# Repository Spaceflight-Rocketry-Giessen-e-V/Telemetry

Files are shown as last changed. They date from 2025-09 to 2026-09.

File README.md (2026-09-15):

# ASCENT Experimental Rocket Telemetry System

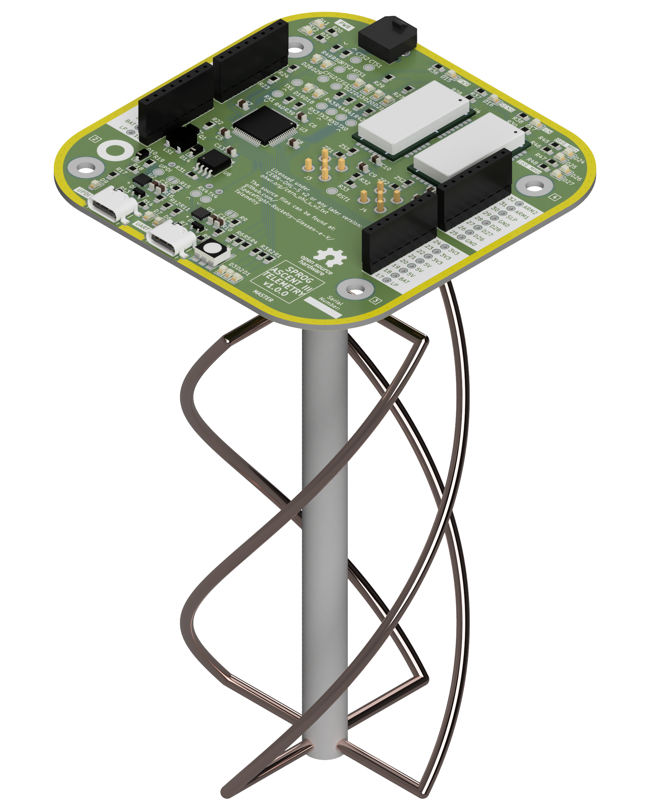
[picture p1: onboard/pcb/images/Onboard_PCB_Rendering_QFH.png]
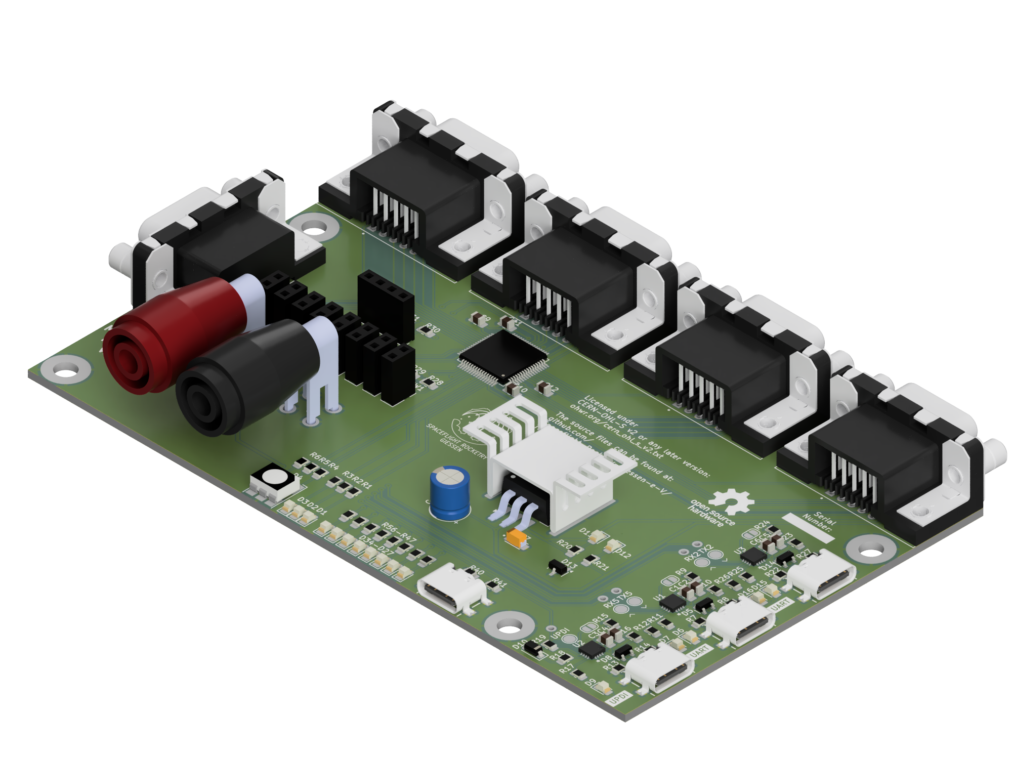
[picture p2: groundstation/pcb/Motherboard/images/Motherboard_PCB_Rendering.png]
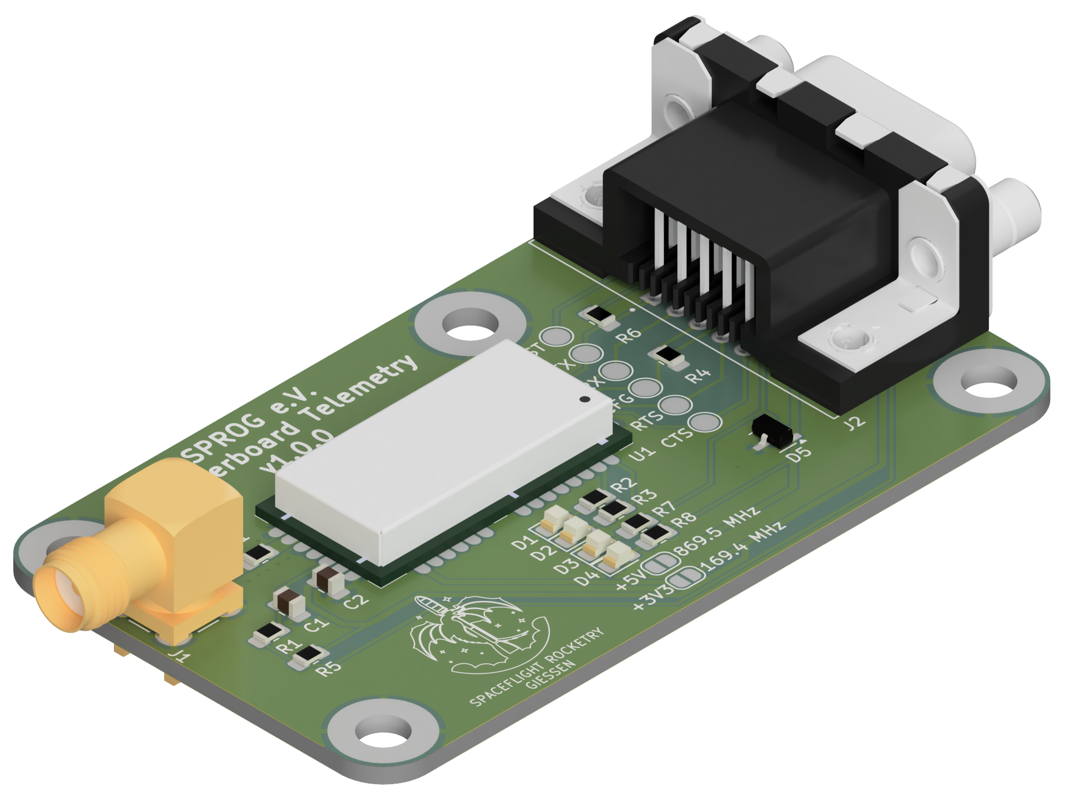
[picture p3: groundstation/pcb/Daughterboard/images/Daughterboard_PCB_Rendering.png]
|</p> | </p></p>|
|---|---|
|<p align="center">[The Onboard System](/onboard/)</p>|<p align="center">[The Groundstation System](/groundstation/)</p>|

---

## Overview

The ASCENT telemetry system is part of the ASCENT flight computer of the student rocketry club [Spaceflight Rocketry Gießen e.V.](https://sprog-ev.de/en/), which is being developed for the PIPE and ARCHER experimental rockets.
This dual-frequency 169/869 MHz telemetry system based on Radiocrafts RC232 radio modules allows bidirectional data exchange between rockets and groundstations with a range of 20 km and a minimum data rate of 1.2 kbps.
The design can easily be adapted for uses outside of rocketry like Smart Home or RC.



## Basic Functionality

- Receiving flight data from the rocket
- Sending radio commands to the rocket
- Displaying live telemetry on a serial monitor or UI

## Actual Performance

In January 2026, we performed our first long range test over a distance of 2 km. Despite poor weather conditions and objects inside the first Fresnel zone, the received signal strength was on par with the theoretical maximum without any unaccounted losses. This test ruled out major design flaws.



This excellent performance was confirmed by multiple medium range tests.

In April 2026, the system was successfully tested on the PIPE 2 rocket to an altitude of 350 m and experienced no link issues during the whole flight.

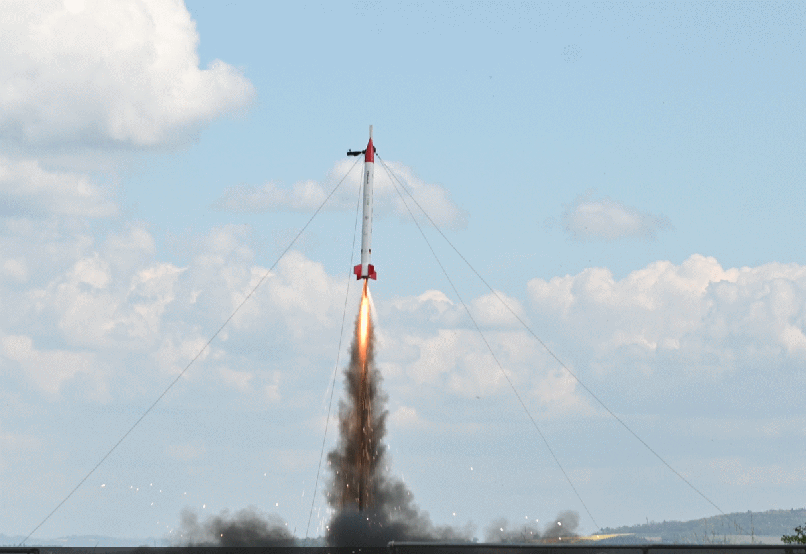
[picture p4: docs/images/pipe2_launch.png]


---

## Repository Contents

This repository contains all files necessary to reproduce the telemetry system, including hardware, firmware, software, and documentation.

### 1. Antenna Hardware

So far, this repository includes [design files](/groundstation/antenna/helical/) and [assembly instructions](/docs/helical_antenna_assembly_manual.md) for our helical 869 MHz groundstation antenna.

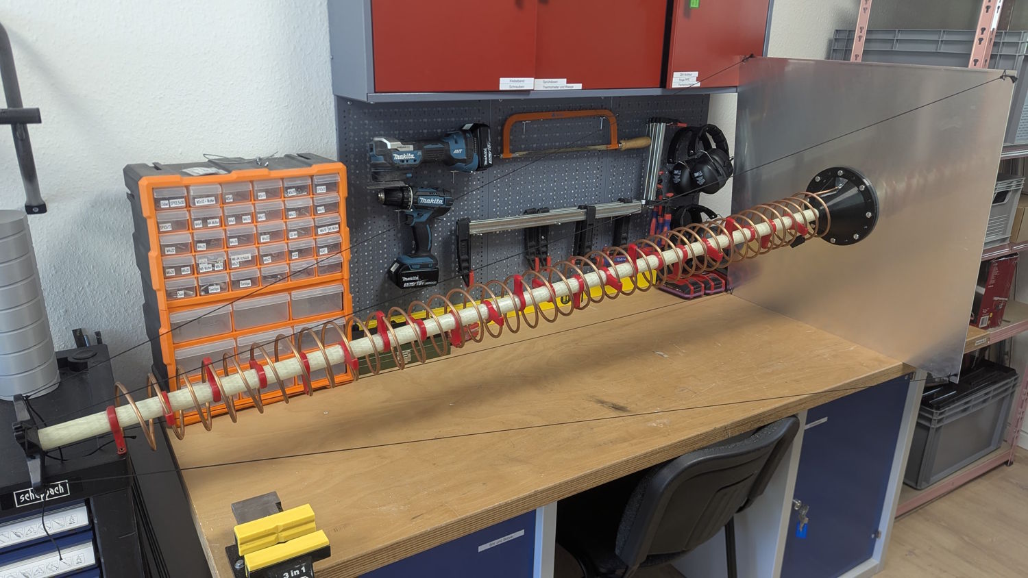
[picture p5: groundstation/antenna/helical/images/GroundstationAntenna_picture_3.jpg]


We also do our own FDTD-simulations which can be found [here](groundstation/antenna/helical/Simulation/Helical_Antenna.m).

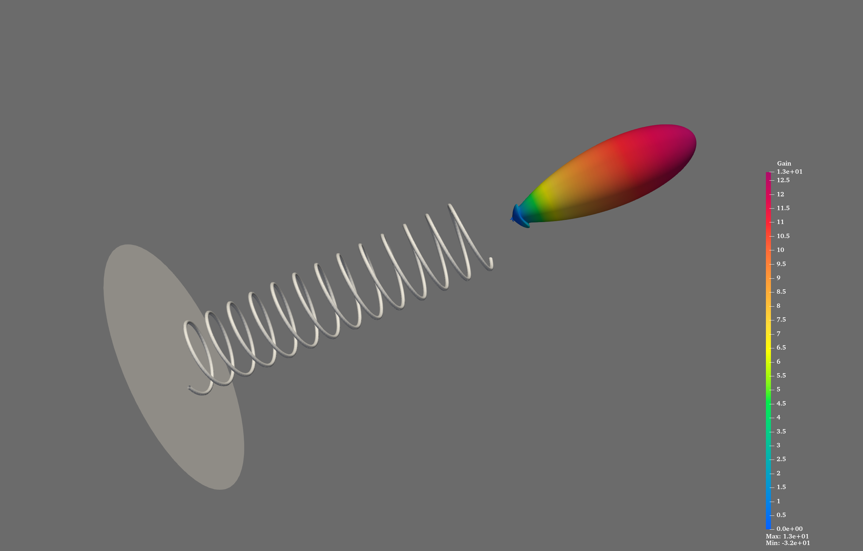
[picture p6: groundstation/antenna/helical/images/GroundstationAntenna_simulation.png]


Currently, we are developing an 869 MHz QFH antenna.

### 2. Electronics Hardware

The telemetry system is based on separate [onboard](/onboard/pcb/) and [groundstation](/groundstation/pcb/) electronics.
The groundstation uses a modular approach with a [motherboard](/groundstation/pcb/Motherboard/) to which up to four [daughterboards](/groundstation/pcb/Daughterboard/) with radio modules can be connected.

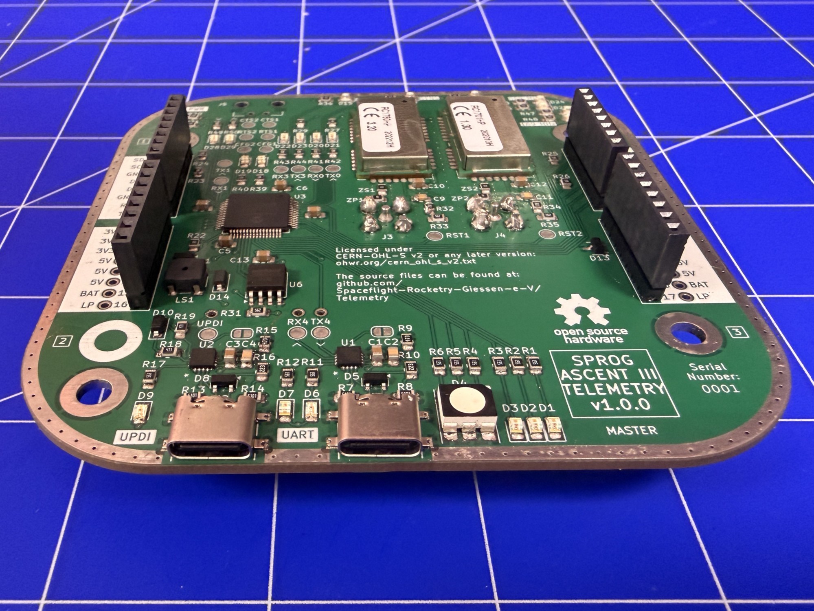
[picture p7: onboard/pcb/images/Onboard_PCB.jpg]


The repository includes for each system the KiCad design files including custom component schematic, footprint, and 3D model libraries, the PDF schematic, the Gerber production files, the bill of material (BOM) and an interactive BOM (iBOM). 
Renderings, images, and 3D models of the electronics are also included.

The [onboard mounting structure](/onboard/mounting%20structure/), the [motherboard and daughterboard casings](/groundstation/casing/) are included separately.

### 3. Firmware

- [Onboard Firmware](/onboard/firmware/)
- [Groundstation Firmware](/groundstation/firmware/) 
- [Radiocrafts RC17xHP-RC232 Library](/libraries/Radiocrafts_RC17xxHP_RC232/)
- [Dynamic Package Codec (Encoding/Decoding) Library](/libraries/DynamicPacketCodec/)
- [Firmware Functions/Classes Reference](https://spaceflight-rocketry-giessen-e-v.github.io/Telemetry/)

### 4. Groundstation UI Software

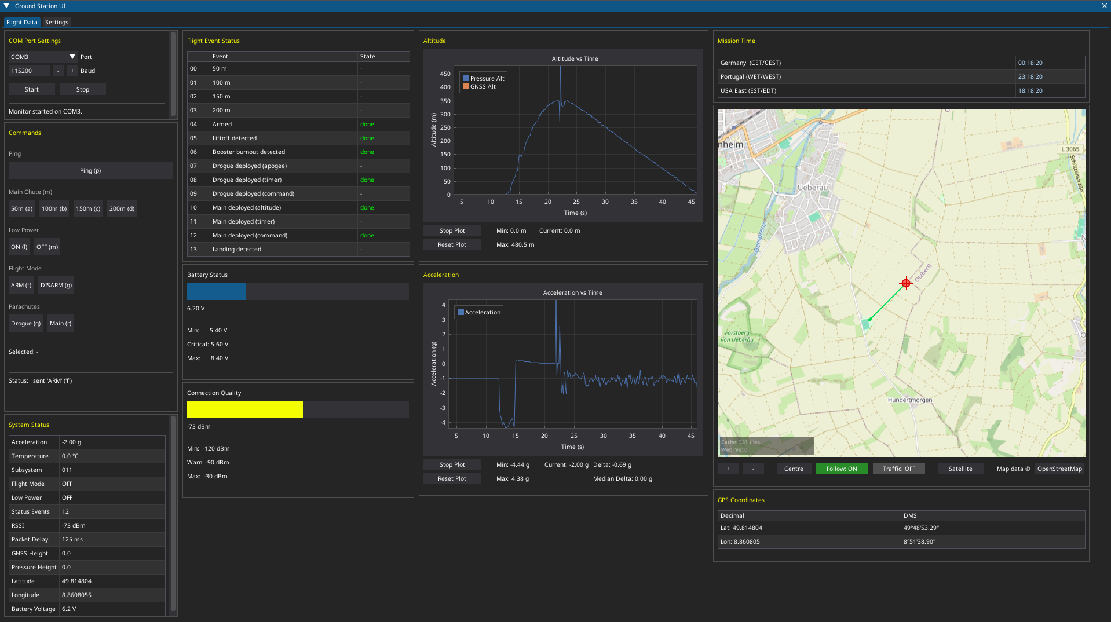
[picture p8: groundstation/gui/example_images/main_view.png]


[Python-based software](/groundstation/gui/) to display live telemetry data on a modern, minimalistic interface with the ability to store flight data and send radio commands. 

Widgets include a GNSS map view, a height plot over time, a acceleration plot over time, a battery voltage indicator with visual warnings, a connection quality indicator with visual warnings and a status event indicator.

### 5. Documentation

- [User Manual](/docs/user_manual.md) and [Operations Cheatsheet](/docs/operations_cheatsheet.md)
- [Design Overview/Rationals](/docs/design_overview.md)
- Documentation of the [Packet Structure](/docs/packet_structure.md) and the [Linkbudget Calculation](/docs/linkbudget.ipynb)
- [And more...](/docs/)

---

## Legal Notice

Please note that radio systems may be subject to local regulations. Ensure that any testing or deployment of these systems complies with national and regional laws regarding RF transmission. The project maintainers are not responsible for misuse or regulatory violations.  

## License

Copyright Spaceflight Rocketry Giessen e.V. 2026<br />
This source describes Open Hardware and is licensed under the CERN-OHL-S v2.<br />
You may redistribute and modify this source and make products using it under the terms of the [CERN-OHL-S v2 or any later version](LICENSE).<br />
This source is distributed WITHOUT ANY EXPRESS OR IMPLIED WARRANTY, INCLUDING OF MERCHANTABILITY, SATISFACTORY QUALITY AND FITNESS FOR A PARTICULAR PURPOSE. Please see the CERN-OHL-S v2 for applicable conditions.<br />
Source location: https://github.com/Spaceflight-Rocketry-Giessen-e-V/Telemetry<br />
As per CERN-OHL-S v2 section 4, should you produce hardware based on this source, you must where practicable maintain the Source Location in its documentation or license information.<br />

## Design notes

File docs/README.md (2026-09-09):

# Documentation

- [Design Overview](/docs/design_overview.md)
    - Design Details
    - Design Rationals
- [User Manual](/docs/user_manual.md)
    - Assembly Instructions
    - Operation Advices
- Libraries Documentation
    - [Radiocrafts RC17xxHP-RC232](/libraries/Radiocrafts_RC17xxHP_RC232/README.md)
    - [Dynamic Packet Codec](/libraries/DynamicPacketCodec/README.md)
- Antenna Documentation
    - [Helical Antenna Design Guide](/docs/helical_antenna_design_guide.ipynb)
    - [Helical Antenna Assembly Manual](/docs/helical_antenna_assembly_manual.md)
    - [Helical Antenna Simulation Guide](/docs/helical_antenna_simulation_guide.md)
    - [QFH Antenna CAD Tutorial](/docs/qfh_antenna_cad_tutorial.md)
- [Operations Cheatsheet](/docs/operations_cheatsheet.md)
    - Commands List
    - Status Events List
    - LED List
- [Packet Structure](/docs/packet_structure.md)
    - General Structure
    - Component Details
- [Linkbudget](/docs/linkbudget.md)
    - Theoretical Foundation
    - Example Calculations

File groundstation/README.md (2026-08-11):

# The Groundstation System

- [Motherboard Electronics Hardware](/groundstation/pcb/Motherboard/)
    - [KiCad Design Files](/groundstation/pcb/Motherboard/)
    - [PDF Schematic](/groundstation/pcb/Motherboard/TelemetryGroundstationMB_Schematic.pdf)
    - [Interactive Schematic / iBOM](/groundstation/pcb/Motherboard/TelemetryGroundstationMB_iBOM.html)
    - [BOM](/groundstation/pcb/Motherboard/TelemetryGroundstationMB_BOM.csv)
    - [Gerber Files](/groundstation/pcb/Motherboard/Production%20Files/)
    - [PCB 3D Model](/groundstation/pcb/Motherboard/TelemetryGroundstationMB.step)
    - [PCB Images](/groundstation/pcb/Motherboard/images/)
- [Daughterboard Electronics Hardware](/groundstation/pcb/Daughterboard/)
    - [KiCad Design Files](/groundstation/pcb/Daughterboard/)
    - [PDF Schematic](/groundstation/pcb/Daughterboard/TelemetryGroundstationDB_Schematic.pdf)
    - [Interactive Schematic / iBOM](/groundstation/pcb/Daughterboard/TelemetryGroundstationDB_iBOM.html)
    - [BOM](/groundstation/pcb/Daughterboard/TelemetryGroundstationDB_BOM.csv)
    - [Gerber Files](/groundstation/pcb/Daughterboard/Production%20Files/)
    - [PCB 3D Model](/groundstation/pcb/Daughterboard/TelemetryGroundstationDB.step)
    - [PCB Images](/groundstation/pcb/Daughterboard/images/)
- [Electronics Casings](/groundstation/casing/)
    - [Motherboard Casing](/groundstation/casing/Motherboard)
    - [Daughterboard Casing](/groundstation/casing/Daughterboard)
- [Firmware](/groundstation/firmware/)
- [869 MHz Helical Antenna](/groundstation/antenna/helical/)
    - [Design Files](/groundstation/antenna/helical/)
    - [Design Guide](/docs/helical_antenna_design_guide.ipynb)
    - [Assembly Manual](/docs/helical_antenna_assembly_manual.md)
    - [Antenna 3D Model](/groundstation/antenna/helical/Antenna%20Assembly.step)
    - [Antenna Images](/groundstation/antenna/helical/images/)
    - [Simulation](/groundstation/antenna/helical/Simulation/)
    - [Simulation Guide](/docs/helical_antenna_simulation_guide.md)
- [Serial Monitor Configuration File](/groundstation/Coolterm_SerialMonitor_Settings.CoolTermSettings)
- [Graphical User Interface](/groundstation/gui/)

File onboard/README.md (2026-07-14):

# The Onboard System

- [Electronics Hardware](/onboard/pcb/)
    - [KiCad Design Files](/onboard/pcb/)
    - [PDF Schematic](/onboard/pcb/TelemetryOnboard_Schematic.pdf)
    - [Interactive Schematic / iBOM](/onboard/pcb/TelemetryOnboard_iBOM.html)
    - [BOM](/onboard/pcb/TelemetryOnboard_BOM.csv)
    - [Gerber Files](/onboard/pcb/Production%20Files/)
    - [PCB 3D Model](/onboard/pcb/TelemetryOnboard.step)
    - [PCB Images](/onboard/pcb/images/)
- [Mounting Structure](/onboard/mounting%20structure/)
- [Firmware](/onboard/firmware/)
- [869 MHz QFH Antenna](/onboard/antenna/) (not yet available)

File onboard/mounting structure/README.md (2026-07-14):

# Electronics Mounting Structure

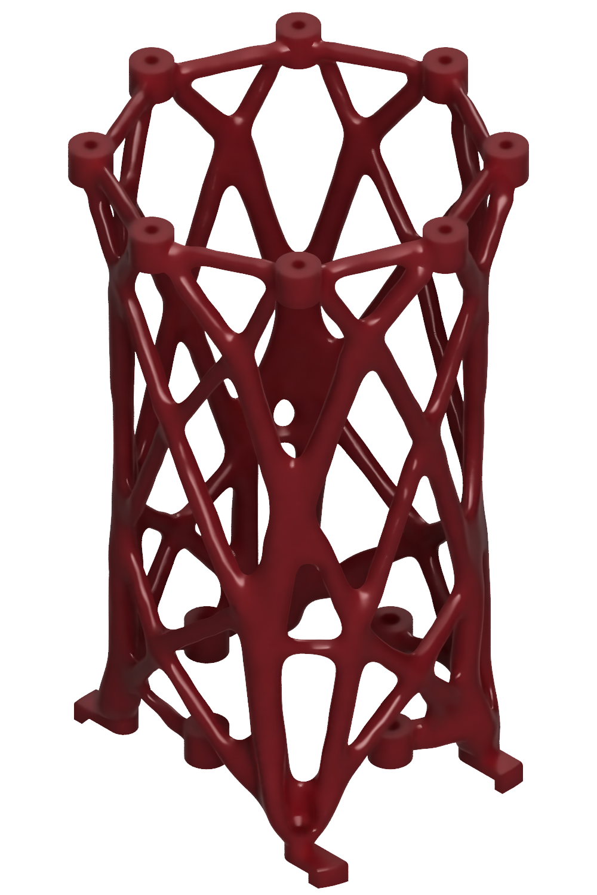
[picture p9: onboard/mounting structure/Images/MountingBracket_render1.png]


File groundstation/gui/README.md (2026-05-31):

# Ground Station UI

A desktop telemetry ground station for monitoring rocketry flights in real time. Built with Python and DearPyGui.

Ground Station UI

---

## Tech Stack

- **Python 3.11+**
- **[DearPyGui](https://github.com/hoffstadt/DearPyGui)** — immediate-mode GUI framework
- **pyserial** — serial communication with the telemetry receiver
- **zoneinfo** — multi-timezone mission clock (stdlib)

---

## UI Overview

The interface is split into two tabs: Flight Data and Settings.

**Flight Data** shows:
- COM port controls (port selector, baud rate, start/stop)
- Command panel with a two-step confirm/abort flow before anything is sent
- Flight event status table (sequential, colour-coded)
- Battery voltage and connection quality (RSSI) progress bars
- Live altitude and acceleration plots with stop/reset/statistics controls
- System status table with the latest decoded packet fields
- Map view with live GPS tracking
- Mission clock in three time zones (Germany, Portugal, US East)

---

## Configuration

All thresholds and labels live in `settings.json` (auto-created on first run). You can edit them through the Settings tab at runtime — changes are written to disk immediately.

Configurable sections:

| Section | What you can change |
| --- | --- |
| `battery` | min / max / critical voltage |
| `connection` | RSSI min / warn / max |
| `flight_events` | event labels, abort threshold |
| `commands` | command groups, button labels, serial codes |

---

## Project Structure

```
├── telemetry/
│   ├── com_controller.py          # Serial receiver thread
│   └── com_monitor_controller.py  # UI-side serial control panel
├── ui/
│   ├── ui_manager.py              # Top-level update dispatcher
│   ├── settings_manager.py        # JSON-backed settings store
│   ├── acceleration_window.py
│   ├── altitude_window.py
│   ├── battery_window.py
│   ├── commands_window.py
│   ├── connection_window.py
│   ├── flight_events_window.py
│   ├── last_packet_window.py
│   ├── location_window.py
│   ├── map_view_window.py
│   ├── settings_window.py
│   └── time_window.py
└── settings.json                  # Auto-generated, edit via Settings tab
```

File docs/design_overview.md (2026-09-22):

# Design Overview

This document provides detailed information about our electronics, firmware, antenna, and GUI systems. It also covers rationales used during the design process.



The whole system is designed for an effective range of 18 km. To accomplish this goal, the signal strength at the receiver must be strong enough to be processed. Our link budget calculation as outlined in [this document](linkbudget.ipynb) ensures that our system meets this requirement.

---

# Table of Contents

- [Electronics](#electronics)
  - [Design Overview](#design-overview-1)
    - [Groundstation MB/DB Approach](#groundstation-mbdb-approach)
    - [Onboard Electronics](#onboard-electronics)
  - [Design Details](#design-details)
    - [Radio Frequencies](#radio-frequencies)
    - [Radio Modules](#radio-modules)
    - [Microcontroller](#microcontroller)
    - [PCB Stackup](#pcb-stackup)
    - [RF Traces](#rf-traces)
    - [USB UPDI Programmer](#usb-updi-programmer)
    - [Staggered Pin Rows / Lock Pattern](#staggered-pin-rows--lock-pattern)
  - [Groundstation Electronics Casings](#groundstation-electronics-casings)
  - [Onboard Electronics Mounting Structure](#onboard-electronics-mounting-structure)
- [Firmware](#firmware)
  - [Onboard Firmware](#onboard-firmware)
  - [Groundstation Firmware](#groundstation-firmware)
  - [Data Budget \& Packet Structure](#data-budget--packet-structure)
  - [Libraries](#libraries)
    - [Radiocrafts RC17xxHP-RC232](#radiocrafts-rx17xxhp-rc232-library)
    - [Dynamic Packet Codec](#dynamic-packet-codec-library)
- [Antennas](#antennas)
  - [Groundstation 869 MHz Helical Antenna](#groundstation-869-mhz-helical-antenna)
    - [Geometric Design](#geometric-design)
    - [Mechanical Design](#mechanical-design)
    - [Simulations](#simulations)
  - [Groundstation 169 MHz Dipole Antenna](#groundstation-169-mhz-dipole-antenna)
  - [Onboard 869 MHz QFH Antenna](#onboard-869-mhz-qfh-antenna)
    - [Geometric Design](#geometric-design-1)
    - [Mechanical Design](#mechanical-design-1)
    - [Simulations](#simulations-1)
- [GUI software](#gui-software)
  - [Architecture](#architecture)
  - [Flight Data Tab](#flight-data-tab)
  - [Settings Tab](#settings-tab)
  - [Data Flow \& Logging](#data-flow--logging)

---

# Electronics

## Design Overview

### Groundstation MB/DB Approach

|  |  |
| :---: | :---: |
| [Motherboard](/groundstation/pcb/Motherboard/)| [Daughterboard](/groundstation/pcb/Daughterboard/)|

The system is based on a modular approach consisting of a motherboard and one or more daughterboards. The motherboard integrates the microcontroller (AVR128DB64), while the daughterboards host the radio modules (RC17xx series).

This architecture allows multiple daughterboards to be connected to the motherboard via a standard 15-pin VGA connector. As a result, different radio modules operating on different frequency bands can be used within the same system.

In the current configuration, the system is designed to use 169.5 MHz for command transmission and 869.5 MHz for telemetry data.

The use of the LEDs is described in the [operations cheatsheet](operations_cheatsheet.md).

### Onboard Electronics

The onboard PCB is based on the standard layout of our rocketry club, featuring a square design with round edges. Power and data are distributed via stackable pin headers located on the left and right sides. Generally, cheap stackable headers which can be found on eBay or Aliexpress can be used. We opted to use [Samtec ESQ pin sockets](https://www.digikey.de/de/products/detail/samtec-inc/ESQ-108-13-G-S/1766188) due to their superior quality. An I2C connection is used for communication with other subsystems to gather sensor data and forward radio commands.

The system includes an RGB LED for status indication, three LEDs for subsystem status indication and five general-purpose LEDs. Additionally, all UART traces feature a LED indicator.

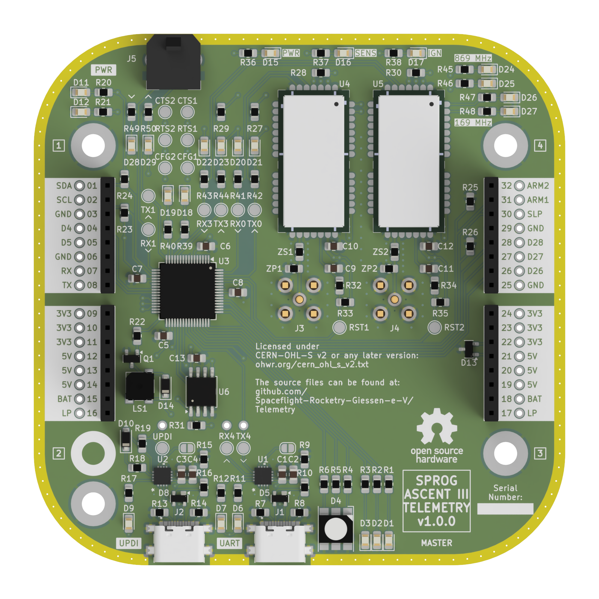
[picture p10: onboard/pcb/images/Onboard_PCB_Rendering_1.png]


### Previous Design

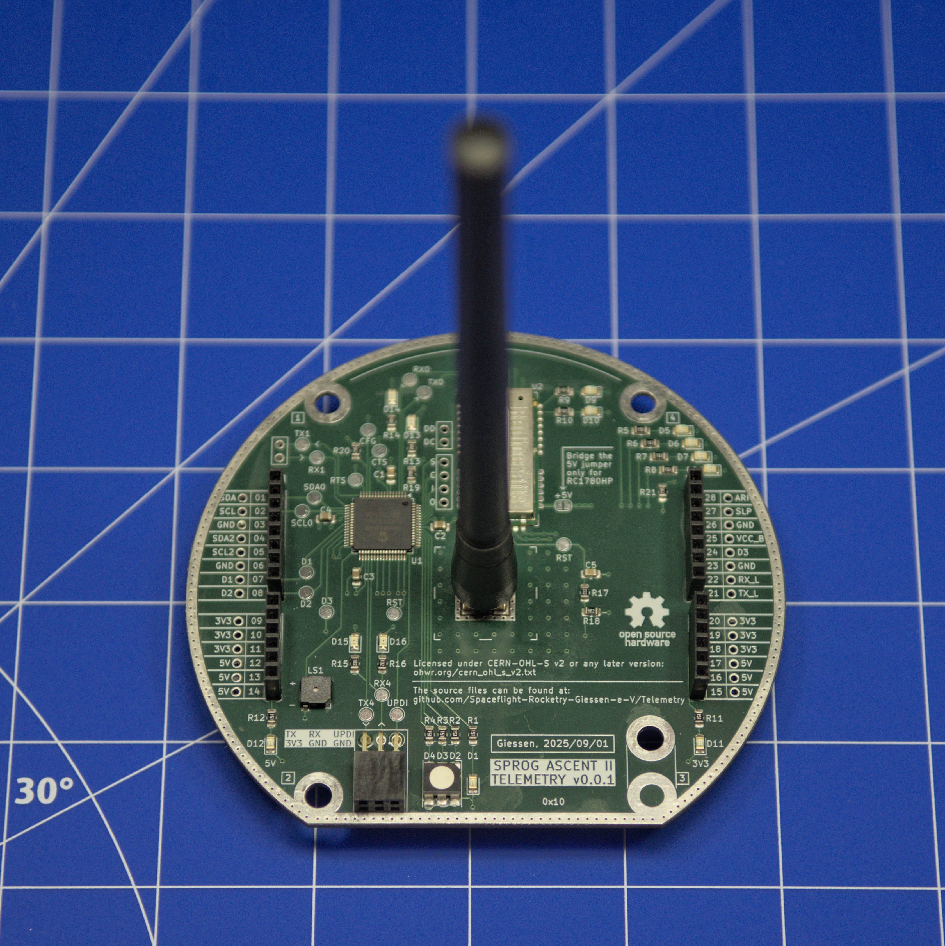
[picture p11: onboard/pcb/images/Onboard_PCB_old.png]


## Design Details

### Radio Frequencies

The license-free frequency bands in Germany are regulated by the Bundesnetzagentur. Frequencies between 100 MHz and 2400 MHz are of primary interest to us. The relevant regulations can be found in the ["Allgemeinzuteilungen von Frequenzen"](https://www.bundesnetzagentur.de/DE/Fachthemen/Telekommunikation/Frequenzen/Allgemeinzuteilungen/start.html). In this case the regulation of SRD devices applies. 

The frequency band between 169.4 MHz and 169.475 MHz can be used with an output power (EIRP) of up to 27 dBm or 500 mW, with a duty cycle of 1 %. This limits the radio transmission to 36 seconds total per (continous) hour.



The frequency band between 869.4 MHz and 869.65 MHz can be used with an output power (EIRP) of up to 27 dBm or 500 mW, with a duty cycle of 10 %. This limits the radio transmission to 6 minutes total per (continous) hour.



### Radio Modules

We chose the Radiocrafts RC17xxHP-RC232 radio modules which come in 169 MHz (RC1701HP) and 869 MHz (RC1780HP) variants. The modules can achieve output powers of up to 27 dBm and the operation is straightforward due to the UART interface. The datasheet can be found [here](https://radiocrafts.com/uploads/RC17xxHP-RC232_Datasheet.pdf). Additionally, there is a separate manual for the RC232 series of radio modules that includes all configuration commands and more information, available [here](https://radiocrafts.com/uploads/RC232_user_manual.pdf). Application notes can be downloaded [here](https://radiocrafts.com/resources/document-library/?rs=Application%20Notes).

The following tables show the available data rates and high power (27 dBm) radio channels of the RC1780HP-RC232 and RC1701HP-RC232 radio modules. The data is taken from the linked datasheet.

|Date Rate #|Data rate|Bandwidth|Modulation|
|---|---|---|--|
|1|tbd.|||
|2|0.3 kbit/s|12.5 kHz|2GFSK|
|3|0.6 kbit/s|12.5 kHz|2GFSK|
|**4**|**1.2 kbit/s**|**12.5 kHz**|**2GFSK**|
|5|2.4 kbit/s|12.5 kHz|2GFSK|
|6|tbd.|||
|7|4.8 kbit/s|12.5 kHz|2GFSK|
|8|9.6 kbit/s|12.5 kHz|4GFSK|
|9|9.6 kbit/s|25 kHz|2GFSK|
|10|19.2 kbit/s|50 kHz|4GFSK|
|11|tbd.|||
|12|38.4 kbit/s|100 kHz|2GFSK|
|13|50 kbit/s|100 kHz|2GFSK|
|14|76.8 kbit/s|200 kHz|2GFSK|
|15|100 kbit/s|200 kHz|2GFSK|

**RC1780HP-RC232 +27 dBm Channels**

|Channel #|Center Frequency|
|---|---|
|57|869.412500 MHz|
|59|869.437500 MHz|
|58|869.462500 MHz|
|60|869.487500 MHz|
|**61**|**869.512500 MHz**|
|62|869.537500 MHz|
|63|869.562500 MHz|
|64|869.587500 MHz|
|65|869.612500 MHz|
|66|869.637500 MHz|

**RC1701HP-RC232 +27 dBm Channels**

|Channel #|Center Frequency|
|---|---|
|**1**|**169.406250 MHz**|
|2|169.418750 MHz|
|3|169.431250 MHz|
|4|169.443750 MHz|
|5|169.456250 MHz|
|6|169.468750 MHz|
|7|169.412500 MHz|
|8|169.437500 MHz|
|9|169.462500 MHz|
|10|169.437500 MHz|

### Microcontroller

We use the AVR128DB64 microcontroller in the 64-pin LQFP version ([datasheet](https://ww1.microchip.com/downloads/en/DeviceDoc/AVR128DB28-32-48-64-DataSheet-DS40002247A.pdf)). It offers a decent improvement compared to beginner-friendly Arduino boards, while still being easy to use. The [AVR DB Arduino Core (DxCore)](https://github.com/SpenceKonde/DxCore) offers excellent firmware and hardware documentation.

The following image shows the pinout of the AVR128DB64 MCU and is taken from the DxCore documentation:



### PCB Stackup

The electronics design (schematic and pcb) was done with the open source EDA software KiCad. We included the KiCad project with all necessary files.

During the pcb design process, we considered the Radiocrafts [RF PCB Layout Recommendation Application Note](https://radiocrafts.com/uploads/AN061_RF_PCB_Layout_Recommendations.pdf) and a [RF PCB Design Guide](https://www.proto-electronics.com/blog/routing-guidelines-rf-pcb). The PCB has a basic 4-layer stackup intended to reduce electromagnetic interference:
1) Components, signal traces, 50 Ohm RF trace
2) Continous ground plane
3) 5 V and 3.3 V power plane
4) Ground plane, signal traces 

Around the edge of the PCB, an exposed ground strip is included, connected by many vias to the solid ground plane (layer 2). The intend is to contain any electromagnetic emissions.

### RF Traces

There are three types of traces commonly used as RF signal traces: microstrip, stripline, and coplanar waveguide. For all types, there are several online calculators to obtain the correct strip width to have a characteristic impedence of 50 Ohms. We use a coplanar waveguide and the calculator included in Kicad.

Some PCB properties like Tmet, RHO, RGH, H, Er, and tand cannot be changed and depend on the PCB manufacturer. JLCPCB lists some parameters like Tmet, H, and Er in [this document](https://jlcpcb.com/impedance). For the other parameters, we used standard values.

For a 4 layer pcb like our onboard pcb: H = 0.2104 mm. For a 2 layer pcb like our groundstation daughterboard pcb: H = 1.6 mm.

For the groundstation daughterboard, our goal was to use the width of the 0805 matching component pads as the trace width and thus a variable separation S. The result is S = 0.22 mm:

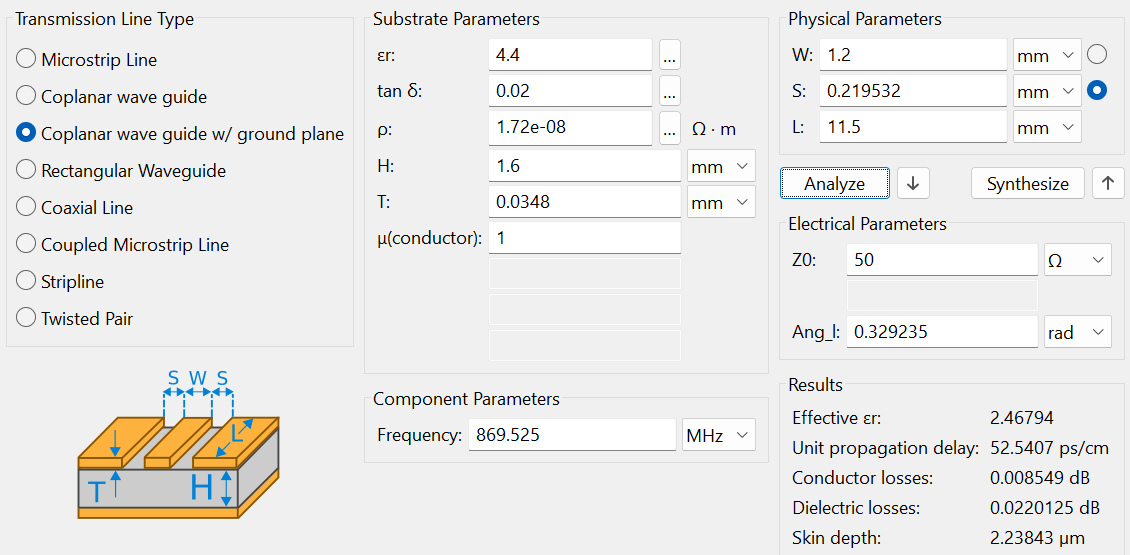
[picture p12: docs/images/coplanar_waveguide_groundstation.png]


Due to the different height of the onboard pcb, a trace width of 1.2 mm would lead to large values for S. Thus, we used a fixed separation S = 0.22 mm (same value as for the groundstation daughterboard) and a variable trace width. The result is W = 0.37 mm. Due to the different width of the matching components, this is not an ideal trace and might have a slighty different impedance. Matching is advised.

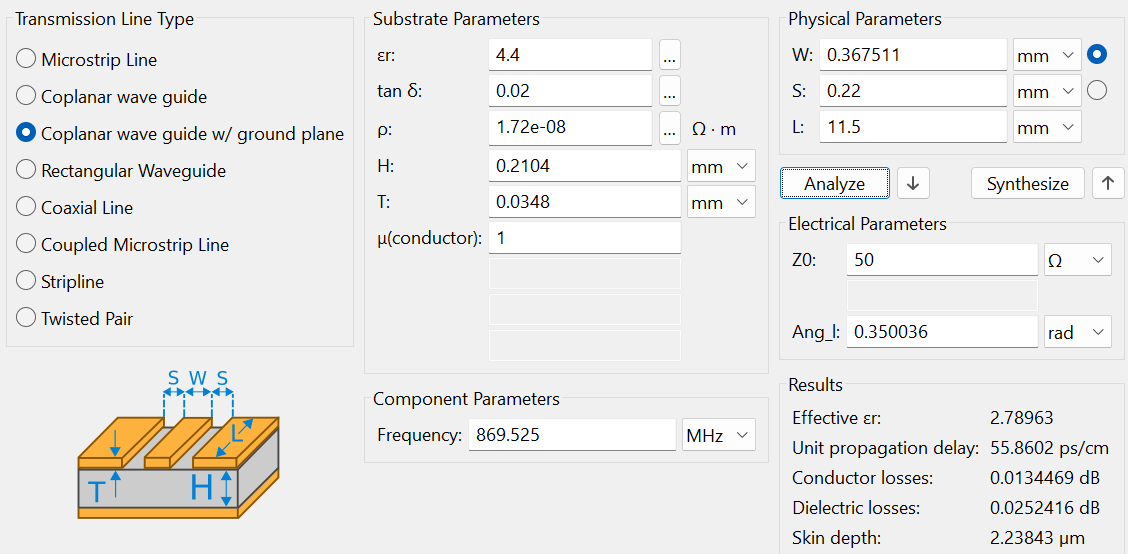
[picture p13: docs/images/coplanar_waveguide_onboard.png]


In the signal trace, a T-matching network is included to be able to match the antenna's impedance to 50 Ohms. When no matching is used, a 0 Ohms resistor has to be connected in series and the parallel component has to be left open. More informations about antenna matching can be found in the [user manual](user_manual.md).

### USB UPDI Programmer

On the onboard and motherboard PCBs, onboard UPDI programmers and USB-UART bridges with USB-C connectors are included. 

The following image shows the general schematic:

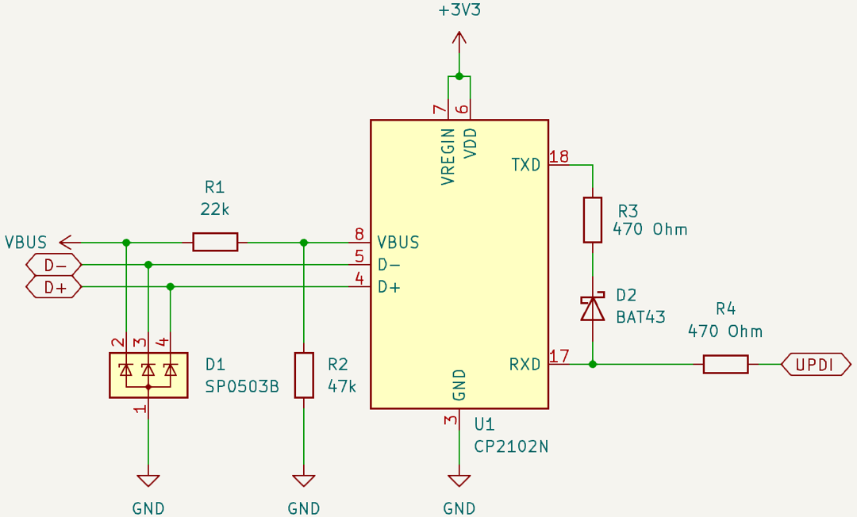
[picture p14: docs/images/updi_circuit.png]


The design features a CP2102N USB to UART bridge, [whose datasheet](https://www.silabs.com/documents/public/data-sheets/cp2102n-datasheet.pdf) suggests the use of an ESD protection diode (D1) for the data lines, and a voltage divider (R1, R2) for the `VBUS` input.
Not shown in the schematic is one LED (with a 560 Ohms resistor) each at `TXT` and `RXT` and decoupling capacitors (4.7 uF and 0.1 uF) at the `VREGIN` and `VDD`.

The UART to UPDI connection is based on [this guide](https://github.com/SpenceKonde/AVR-Guidance/blob/master/UPDI/jtag2updi.md). It features a Schottky diode and two protection resistors.

### Staggered Pin Rows / Lock Pattern

The onboard electronics feature a total of four stackable pin headers used to connect all subsystems of the rocket flight computer to a PCB stackup. Without precise alignment, the stacking of multiple PCBs is impossible.<br>
To fullfill this requirement, we use high-quality [Samtec ESQ pin sockets](https://www.digikey.de/de/products/detail/samtec-inc/ESQ-108-13-G-S/1766188) and a staggered pin layout inspired by an old [Sparkfun article](https://web.archive.org/web/20241202225923/https://www.sparkfun.com/tutorials/114), which is only available on the Wayback Machine nowadays.

The pins are staggered to guarantee perfect alignment. A shift by 1/10" or 0.254 mm and a hole size of 1 mm is perfect for the Samtec ESQ pin sockets. The result looks like this:

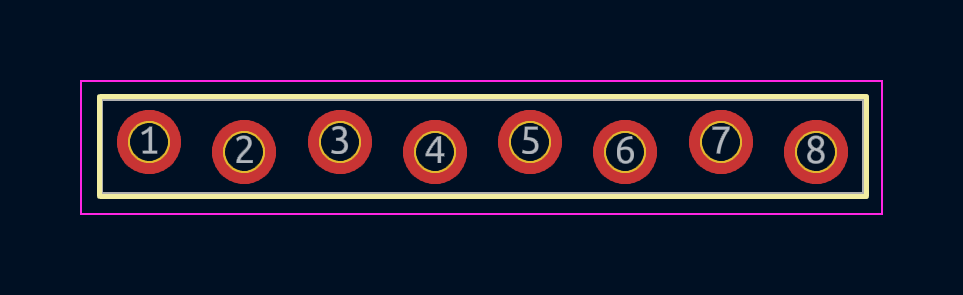
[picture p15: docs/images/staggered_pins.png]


## Groundstation Electronics Casings

Plastics enclosures for the motherboard and daughterboards, each with a bottom part, a shell, and an acrylic cover. The repository includes all the original Fusion and auxiliary (`.step`, `.stl`) design files.

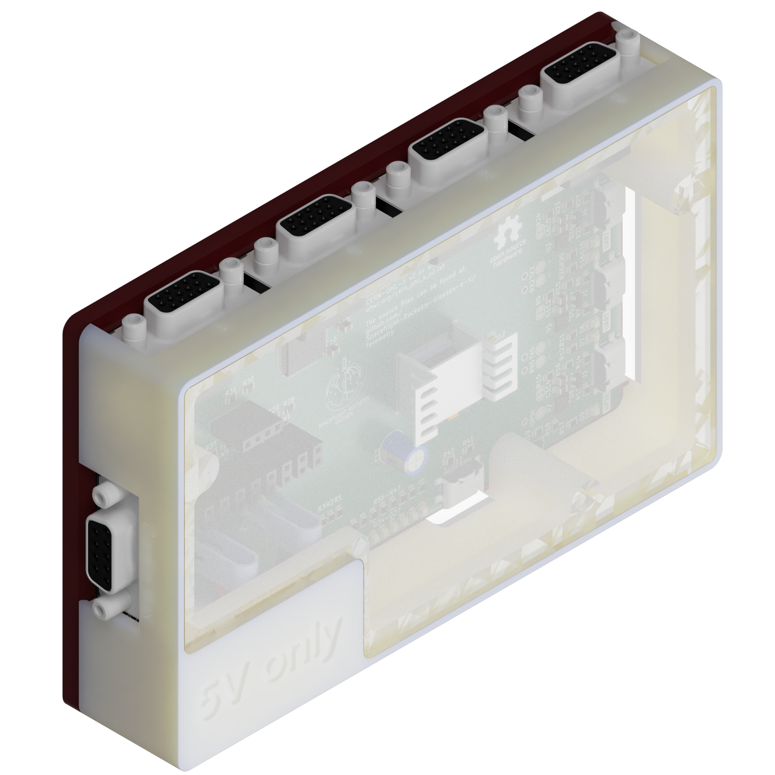
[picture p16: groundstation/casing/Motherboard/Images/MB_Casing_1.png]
Motherboard Casing
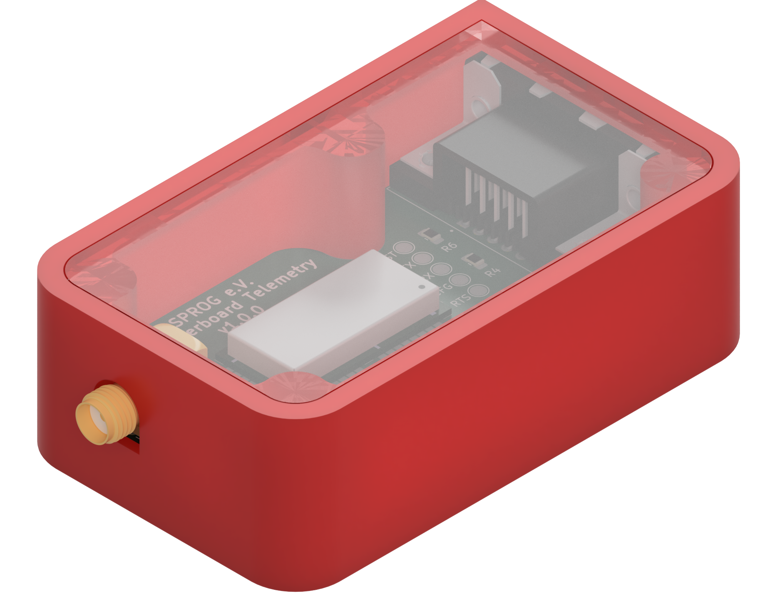
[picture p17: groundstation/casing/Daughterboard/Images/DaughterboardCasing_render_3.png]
Daughterboard Casing
|||
|:---:|:---:|
|[Motherboard Casing](/groundstation/casing/Motherboard/)|[Daughterboard Casing](/groundstation/casing/Daughterboard/)|

## Onboard Electronics Mounting Structure

Attachment for onboard pcb, onboard QFH antenna and attachment point inside the rocket. Designed with generative design. The original and auxiliary design files can be found [here](../onboard/mounting%20structure/)



---

# Firmware

An overview of all functions and classes is given in the [Firmware Code Reference](https://spaceflight-rocketry-giessen-e-v.github.io/Telemetry/).

## Firmware Overview

> Outdated, can be removed as soon as the other information is filled in. See [#71](/../../issues/71)

The firmware structure may be seen in the image below.



In the setup function, pin declarations and starting conditions are established. The radio module is initialized, and the desired configurations are applied after a configuration reset. Additionally, the flight computer initializes the I2C connection to the other subsystems of the flight computer (such as sensorics) and the ground station initializes the UART connection to the ground station computer.

In the loop function, radio commands (such as ping, toggle flight mode, toggle low power mode) are exchanged and data from the subsystems is collected and also exchanged. The available radio commands are listed in the [operations cheatsheet](operations_cheatsheet.md).

## Onboard Firmware

> Informations will be added. See [#71](/../../issues/71)

### I2C Subsystems

`i2c_connectivity.h` etc.

### Downlink Time Surveillance

6 min in 60 mins

### Flight/Telemetry Data Packets

Every 10th packet in flightmode is telemetry. Every 2nd packet in standby is telemetry.

### Loop Frequency Control

Dynamic Timer

## Groundstation Firmware

> Informations will be added. See [#71](/../../issues/71)

Limitations:
- No dynamic detection of daughterboards

### Daughterboard Modularity

No modularity yet, no dynamic module recognition.

### Not Implemented Features

D-Sub 9 from mission control, display, buttons.

## Data Budget \& Packet Structure

To achieve the highest possible range, we opted to use a low data rate, specifically 1.2 kbps. As a compromise between sampling rate and packet size, we chose a sampling rate of 10 Hz, resulting in 120 bits or 15 bytes per packet. Since the data link should not operate at full capacity, we allocate a buffer of 20%, leading to a final packet size of 12 bytes.

The structure of each packet with its components is described [here](package_structure.md).
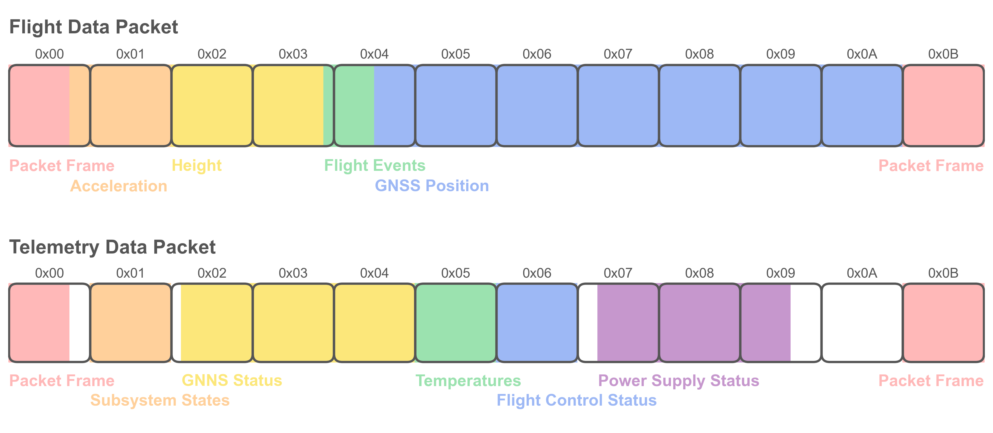
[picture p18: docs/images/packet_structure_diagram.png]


To consider the 10 % duty cycle, the flight computer usually only transmits once every few seconds (the rate can be configured). The module starts to transmit continuously when the flight mode is toggled by a radio command. After a preset time, the continuous transmission stops and the standby transmission once every few seconds starts again.

## Libraries

Both included libraries underly the same Open-Source license as the parent project and are published to the [PlatformIO library registry](https://registry.platformio.org/search?q=owner%3Asprog-ev).

### Radiocrafts RX17xxHP-RC232 Library

To ensure high modularity and a clean codebase, we created a [RC17xxHP-RC232 code library](../libraries/Radiocrafts_RC17xxHP_RC232/) together with its documentation. The library includes functions for configuring the module, read sensor data and reset the module.

The included functions can be easily adapted for other uses and other radio modules like the RC11xxHP-RC232 series.

### Dynamic Packet Codec Library

The encoding and decoding of packets according to our [packet structure](packet_structure.md) is handled by the [Dynamic Library Codec Library](../libraries/DynamicPacketCodec/). It dynamically encodes and decodes data components and handles the packet framing and can again easily be adapted and expanded.

---

# Antennas

Previously, we only used dipole stick antennas ([Linx ANT-868-CW-HW-SMA](https://www.digikey.de/en/products/detail/te-connectivity-linx/ANT-868-CW-HW-SMA/5592340)) for our telemetry system. Currently, we develop own antennas to be able to adapt them to our specific needs. Our plan is to use a QFH antenna with an omnidirectional radiation pattern on the flight computer and a directional helical antenna on the ground side.

## Groundstation 869 MHz Helical Antenna

### Geometric Design

We have included a separate [Helical Antenna Design Guide Python Notebook](/docs/helical_antenna_design_guide.ipynb). It describes the design process based on [this paper](https://bpb-us-e1.wpmucdn.com/sites.gatech.edu/dist/4/463/files/2015/06/HelixAPMagazineSubmission.pdf?bid=463) and the necessary calculations. There is also a Fast-Track calculation which approximates the calculations and needs only the frequency $f$, the wire radius $r$ and the ratio of length to circumference $\frac{L}{C}$.

More informations about helical antennas can be found [here](https://www.microwaves101.com/encyclopedias/helix-antennas) and [here](https://jcoppens.com/ant/helix/index.en.php).

The general process follows these steps:
1) Specify absolute circumference based on $\frac{L}{C}$
2) Specify pitch angle based on $\frac{L}{C}$
3) Calculate all other parameters and estimate the gain

The following table summarizes the geometric parameters of our helical groundstation antenna: 

| Parameter | Symbol | Value |
| --- | --- | --- |
| Frequency | f | 869.525 MHz |
| Wavelength | λ | 344.7773 mm |
| Circumference | C | 344.7773 mm |
| Diameter | D | 109.7460 mm |
| Radius | R | 54.8730 mm |
| Length | L | 480.1482 mm |
| Pitch angle | α | 6.0° |
| Pitch distance | d | 36.2376 mm |
| Turns | N | 13.25 |
| Wire radius | r | 3 mm |
| Wire length | l | 4.618 m |

The antenna has a gain of $G = 16.5\,\mathrm{dBi}$.

### Mechanical Design

To realise this long antenna design, some kind of fixature is necessary since the copper pipe would otherwise act as a spring.

As a central support, we use a 31 mm wide glass fiber rod. With epoxy resin, we attach a 3D printed support structure called pacifier every 1.75 turns. The prewound copper pipe can be wound through the pacifiers, which then leads to a supported structure.

The glass fibre rod sticks through the 40 cm round aluminium ground plane and is held in place by two cone shaped 3D printed support structures, attached with epoxy resin to the GFK rod. The cones are in turn attached to each other with eight M6 bolts through the ground plane. There is a fixture included in the bottom cone which attached to a camera tripod.

The following image shows the groundplane, the upper cone support, the GFK rod, the pacifiers and the copper cable:

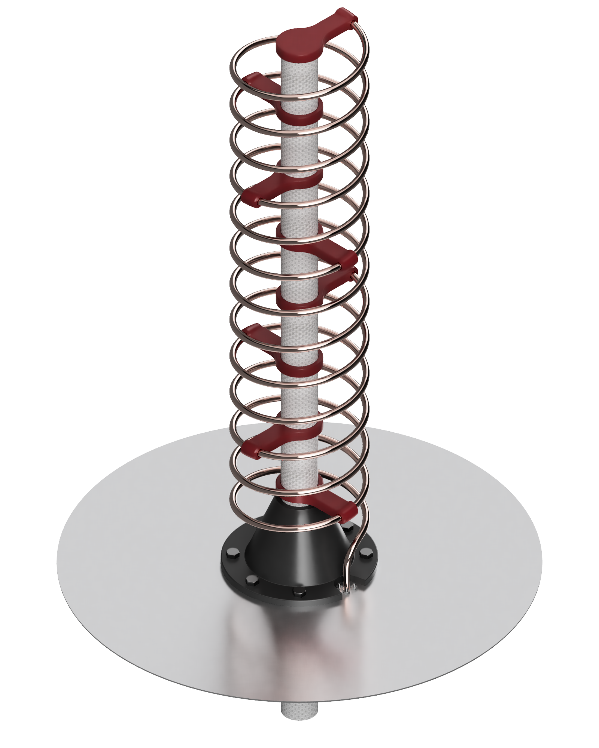
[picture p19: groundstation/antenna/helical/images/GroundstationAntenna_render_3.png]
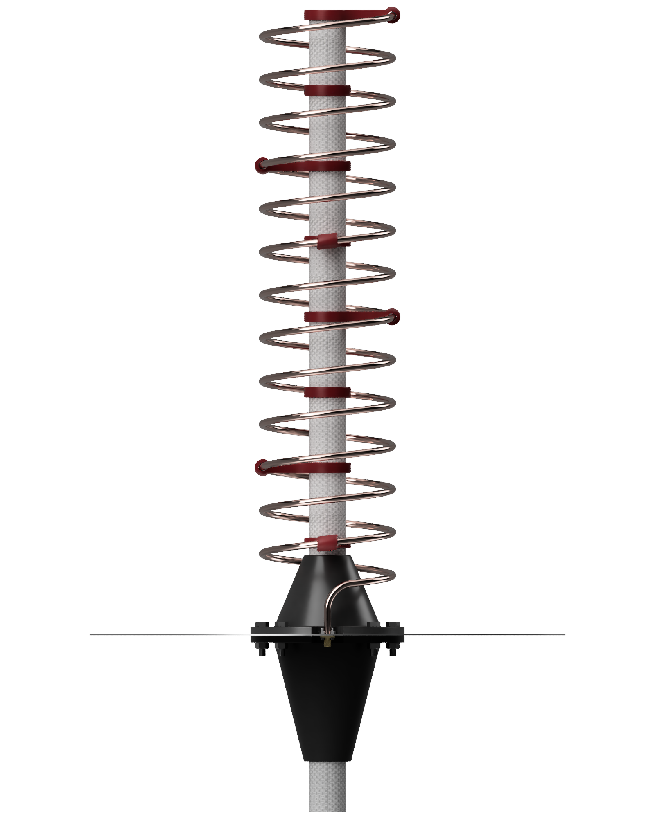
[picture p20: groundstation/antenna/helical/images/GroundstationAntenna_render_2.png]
Side View
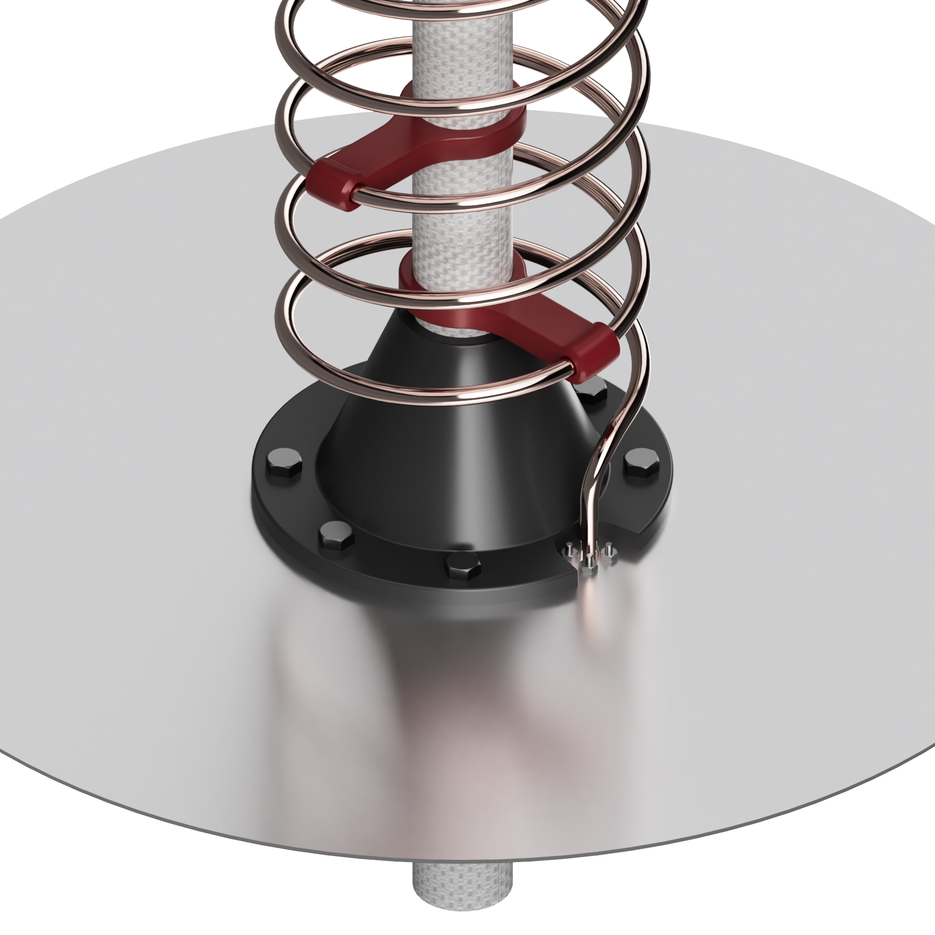
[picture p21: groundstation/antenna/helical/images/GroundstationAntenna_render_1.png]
| |  |  |
|---|---|---|

The assembly informations can be found in the [user manual](user_manual.md).

The winding help is a mould for shaping the copper wire. Since the wire expands a bit after winding, we decreased the size of the winding help by 3 %, leading to a diameter $D = 106.4536\,\mathrm{mm}$.

### Simulations



The simulations are based on the Finite-Difference Time-Domain (FDTD) method provided by the [openEMS software](https://github.com/thliebig/openEMS-Project). This allows us to look at the performance of the antenna nefore we build it and home in during the design process regarding the geometry.
The guide to the simulation can be found [here](helical_antenna_simulation_guide.md)
### Previous Design

Before the design process of the new helical antenna, we designed and built a much larger version, featuring a 1.5 m helix and a 70 cm x 70 cm x 2 mm ground plane. The resulting antenna was too large, heavy and expensive, which is why we settled on a 0.5 m helix with a round 40 cm x 1.5 mm ground plane. The new antenna can easily be mounted on a camera tripod.



## Groundstation 169 MHz Dipole Antenna

The groundstation antenna for the 169 MHz radio system consists of a simple [dipole antenna](https://www.digikey.de/de/products/detail/joymax-electronics/VHX-362BSA1B/27545755) with an aluminum reflector.

A male-to-male panel-mount sma connector connects the coaxial cable, the reflector and the dipole antenna.

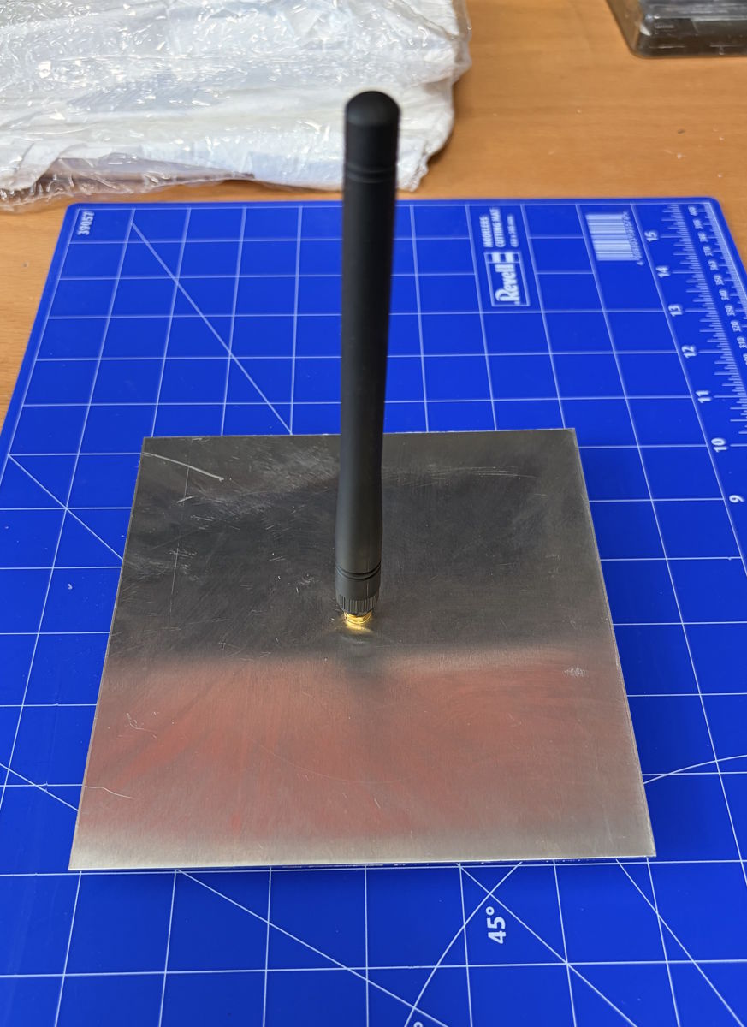
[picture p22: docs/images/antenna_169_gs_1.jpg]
Antenna Assembly
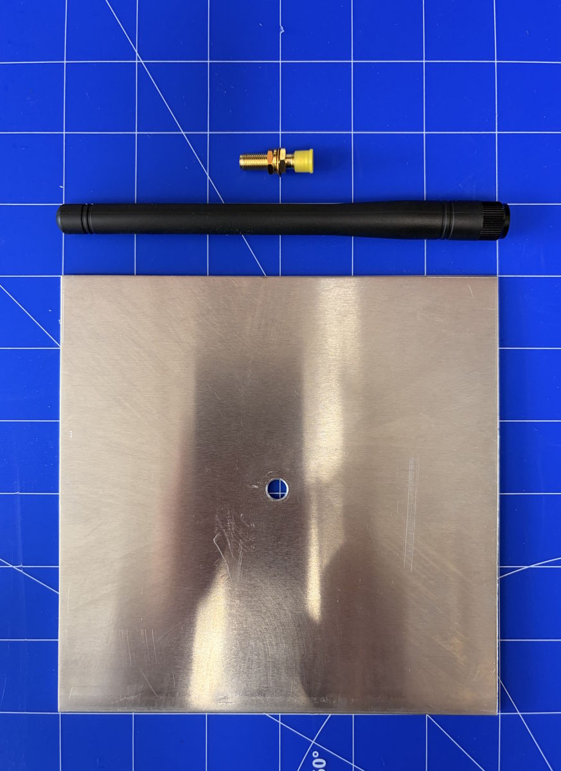
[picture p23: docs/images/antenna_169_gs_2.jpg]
Antenna Components
|||
|---|---|

## Onboard 869 Mhz QFH Antenna

> Informations will be added. See [#43](/../../issues/43)

### Geometric Design

Many resources on antennas: [antenna-theory.com](https://www.antenna-theory.com/)

Information on QFH antennas: [jcoppens.com](https://jcoppens.com/ant/qfh/index.en.php)

Information on connecting QFH antennas: [jcoppens.com](https://jcoppens.com/ant/qfh/adapt.en.php)

### Mechanical Design

### Simulations

---

# GUI software

The ground station GUI is a desktop telemetry dashboard for monitoring a flight in
real time. It is written in Python and built on [DearPyGui](https://github.com/hoffstadt/DearPyGui),
an immediate-mode GUI framework. The application reads the decoded telemetry stream
from the ground station receiver over the serial (UART) link, visualises it across a
set of live windows, logs everything to disk, and lets the operator send radio
commands back to the flight computer. The code lives in [/groundstation/gui/](/groundstation/gui/);
see its [README](/groundstation/gui/README.md) for setup and run instructions.



## Architecture

The application is started from [main.py](/groundstation/gui/main.py), which hands off to
the `UIManager` (`ui/ui_manager.py`). The `UIManager` builds the DearPyGui viewport,
instantiates every window, and acts as the central dispatcher for incoming telemetry.

Telemetry ingestion is handled by a `TelemetryReceiver` (`telemetry/com_controller.py`)
running on a background daemon thread. It reads the serial port line by line, matches
each line against a set of per-field regular expressions, and assembles a complete
packet once all expected fields have arrived. Completed packets are pushed to
`UIManager.update_all()`, which fans the individual fields out to the relevant windows.

All thresholds, labels and command definitions are kept in a JSON file
(`ui/settings.json`) managed by a `SettingsManager`. Values are accessed by
dot-notation (e.g. `battery.voltage_min`) and can be changed at runtime through the
Settings tab, with edits written back to disk immediately.

The GUI is single-window with two tabs. Several background threads run alongside the
main DearPyGui loop: the serial receiver, a map tile-fetch worker pool, and (optionally)
an air-traffic poller for the map overlay.

## Flight Data Tab

The Flight Data tab is the operational view and arranges the live windows in columns:

| Window | Purpose |
| --- | --- |
| COM Controller | Select the serial port and baud rate and start/stop the telemetry receiver. |
| Commands | Send radio commands (ping, flight mode, low power, parachute/main chute) with a two-step confirm/abort flow so nothing is sent by a single misclick. |
| Last Packet | Read-only table showing the latest decoded value for every telemetry field. |
| Flight Events  | Sequential, colour-coded event list (pending → done → abort) driven by the packet status field. |
| Battery | Voltage progress bar with an under-voltage warning against configurable thresholds. |
| Connection | RSSI signal-quality bar with a red→yellow→green gradient and a weak-signal warning. |
| Altitude | Live plot of barometric (pressure) and GNSS altitude with min/max/current statistics and stop/resume/reset controls. |
| Acceleration | Live acceleration plot in g, with min/max/current and sample-to-sample delta statistics. |
| Time | Mission clock shown in three time zones (Germany, Portugal, US East). |
| Map View | Interactive OpenStreetMap view with live GPS track, pan/zoom, follow-the-rocket centring, cached tiles, and an optional live air-traffic overlay (OpenSky Network). |
| GPS Location | Current coordinates in both decimal degrees and degrees/minutes/seconds. |

## Settings Tab

The Settings tab exposes the contents of `settings.json` as editable fields, so the
operator can tune the dashboard without leaving the application. Changes are persisted
immediately. The configurable sections are:

| Section | Controls |
| --- | --- |
| `battery` | Minimum, maximum and critical voltage |
| `connection` | RSSI minimum, warning and maximum |
| `flight_events` | Event labels and the abort threshold |
| `commands` | Command groups, button labels and serial codes |

## Data Flow & Logging

A packet travels from the hardware to the screen as follows:

```
Receiver hardware (UART)
    - TelemetryReceiver: read line, regex-match fields, assemble packet
    - UIManager.update_all(packet): dispatch fields to windows
    - individual windows: altitude, acceleration, battery, connection,
      map/GPS, flight events, last-packet table
```

Every session is logged to disk under `groundstation/gui/logs/`: a `.txt` file
captures the raw serial lines with timestamps, and a `.csv` file records one row per
complete packet for post-flight analysis.

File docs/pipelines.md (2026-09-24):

# Updating Pipelines Guide

This document provides an overview of the automated GitHub Actions workflows and the manual processing pipelines used when updated parts of this project. It is meant as an internal guide but can also provide support when contributing to or working on the project.

# Table of Contents

- [Automatic](#automatic)
   - [Firmware Documentation](#firmware-documentation)
- [Manuell](#manuell)
   - [Updating PCBs](#updating-pcbs)
   - [Updating CAD Models](#updating-cad-models)
   - [Updating Libraries](#updating-libraries)

# Automatic

## Firmware Documentation

The firmware documentation workflow automatically builds and publishes the API documentation for the onboard firmware, ground-station firmware, and libraries. The documentation is generated from comments and declarations in the C/C++ source files.

The source code uses Doxygen comment syntax to provide structured information about functions, classes, and data structures. A documentation block starts with `/**` and is placed directly before the declaration it describes. Doxygen commands beginning with `@` identify the purpose and individual parts of the API:

- `@brief` provides a short summary.
- `@param` describes a function parameter.
- `@return` describes the return value.
- `@defgroup` creates a documentation group.
- `@ingroup` assigns a declaration to a group, such as `onboard` or
  `groundstation`.

For example:

```cpp
/**
 * @brief Reads the latest command from the USB serial interface.
 *
 * @param serialUSB Serial interface used to receive the command.
 * @return The received command value.
 * @ingroup groundstation
 */
uint8_t commandReceive(HardwareSerial *serialUSB);
```

During the workflow, Doxygen converts these comments and the associated C/C++ declarations into Markdown/HTML files. 


The workflow runs after a push to the `main` branch when files in one of the following locations change:

- [`onboard/firmware/`](/onboard/firmware/)
- [`groundstation/firmware/`](/groundstation/firmware/)
- [`libraries/`](/libraries/)
- [`.github/mkdocs/`](/.github/mkdocs/)
- [`.github/workflows/mkdocs_workflow.yml`](/.github/workflows/mkdocs_workflow.yml)

The GitHub Actions job performs these steps:

1. Checks out the repository and configures the GitHub Actions bot as the Git user.
2. Installs Python 3.12, Doxygen, MkDocs, Material for MkDocs, and MkDoxy.
3. Builds the complete documentation using the configuration in    [`.github/mkdocs/mkdocs.yml`](/.github/mkdocs/mkdocs.yml).
4. Runs the build in strict mode so that documentation warnings cause the job to fail instead of deploying an incomplete site.
5. Publishes the generated website to the [`gh-pages` branch](https://spaceflight-rocketry-giessen-e-v.github.io/Telemetry/).

The published firmware documentation is available at [spaceflight-rocketry-giessen-e-v.github.io/Telemetry](https://spaceflight-rocketry-giessen-e-v.github.io/Telemetry/). If another documentation workflow starts while one is already running, the older run is cancelled so that only the newest version is deployed.

# Manual

## Updating PCBs

When updating anything related to PCBs, work through the follwing steps:

1) Regenerate pdf schematic
2) Regenerate gerber files 
3) Zip the gerber files
4) Regenerate bom and ibom
5) Check if all renderings are still right

Please always check that no custom third party symbols, footprints or 3D models are included in the custom libraries. Instead, substitutions should be handcrafted (KiCad objects can be used as a starting point as stated [here](https://www.kicad.org/libraries/license/)). Please also remove unused symbols, footprints and 3D models.

## Updating CAD Models

When updating a CAD model in Autodesk Fusion, the `.f3d`/`.f3z` file should be used as the starting point. 

After the changes, the `.f3d`/`.f3z` file should be exported and placed in the `Original Design Files` folder. Also, every component should be exported separately as both `.stl` and `.step` files and both should be placed in the `Auxiliary Design Files` folder.

It should always be checked, if all renderings are still right even after the changes.

## Updating Libraries

When one of the libraries is updated, the version number in the `library.json` file has to be incremented. This project adheres to Semantic Versioning with MAJOR.MINOR.PATCH as the version number. Please see the [Semantic Versioning v2.0.0 Specification](https://semver.org/spec/v2.0.0.html) for details.

To publish the library to the [PlatformIO Library Registry](https://registry.platformio.org/), the PlatformIO Core CLI tool has to be used. First, open only the library folder in VS Code. Then, click the PlatformIO Icon in the side bar and go to `Miscellaneous` &rarr; `PlatformIO Core CLI`. Use `pio account login` to log in to the PlatformIO account and then use `pio pkg publish` to publish the new library version.

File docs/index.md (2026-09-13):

# ASCENT III Telemetry Firmware

API documentation for the onboard and ground-station firmware of the
ASCENT III telemetry system, including its packet codec and Radiocrafts
radiomodule libraries.

## Firmware documentation

- [Onboard firmware](onboard/group__onboard.md)  
  Functions, classes, and source file documentation for the rocket's
  onboard telemetry firmware.

- [Groundstation firmware](groundstation/group__groundstation.md)  
  Functions, classes, and source-file documentation for the ground-station
  controller.

## Library documentation

- [DynamicPacketCodec](packet/annotated.md)  
  Encoding and decoding of telemetry and command packets.

- [Radiocrafts RC17xxHP-RC232](radiocrafts/annotated.md)  
  Interface library for the Radiocrafts radio modules.

## About this documentation

The API reference is generated from the source code using
[MkDoxy](https://github.com/JakubAndrysek/MkDoxy). The website is built
with [MkDocs](https://www.mkdocs.org/) and the
[Material for MkDocs](https://squidfunk.github.io/mkdocs-material/) theme.

For hardware files, manuals, and project information, visit the
[Telemetry repository](https://github.com/Spaceflight-Rocketry-Giessen-e-V/Telemetry).

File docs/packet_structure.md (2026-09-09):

# Radio Packet Structure

- [Data Budget](#data-budget)
- [Flight Data Packet Structure](#flight-data-packet-structure)
- [Telemetry Data Packet Structure](#telemetry-data-packet-structure)
- [Frame Components](#frame-components)
- [Data Components](#data-components)



---

## Data Budget

With the data rate of 1.2 kbps, the desired sampling rate of 10 Hz and the desired packet size of 12 bytes a buffer of 20 % or 3 bytes per packet is retained to guarantee a robust and reliable data exchange.

This document describes the specific use of the 12 byte data packets.
We distinguish between [Flight Data Packets](#flight-data-packet-structure-overview), which are being sent 9 times every second, and [Telemetry Data Packets](#telemetry-data-packet-structure-overview), which are being sent once every second.

The encoding and decoding of the data packets is carried out by the included [Packet Library](/../common/libraries/Packet/).

The groundstation appends the received signal strength RSSI as the 13th byte (#12 in the following tables) during receiving. This byte is thus not transmitted and not present in the library encode functions.

## Flight Data Packet Structure

The Flight Data Packets include data necessary for mission control during flight to confirm a successful launch.

The following table lists the components of each Flight Data Package. 

| Byte position | Use | Size | Value Range | Resolution |
| --- | --- | --- | --- | --- |
| 0 | [COBS](#cobs) | 4 bits | 0 to 10 | / | 
| 0 | [Parity Bit](#parity-bit) | 1 bits | 0 or 1 | / |
| 0 | [Packet Identifier](#packet-identifier) | 1 bit | 0 | / |
| 0 to 1 | Acceleration | 10 bits | -17 g to 17.1 g | 0.03333 g |
| 2 to 3 | Height (Pressure) | 15 bits | 0 to 6553.4 m | 0.2 m |
| 3 to 4 | [Flight Events](#flight-events) | 5 bits | 0 to 31 | / |
| 4 to 7 | [GNSS Latitude](#latitude-longitude) | 26 bits | -90° to 90° | 0.0000026823° |
| 7 to 10 | [GNSS Longitude](#latitude-longitude) | 26 bits | -180° to 180° | 0.0000053645° |
| 11 | [End Byte](#end-byte) | 8 bits | `0xEE` | / |
| 12 | RSSI | 8 bits | -127.5 dBm to 0 dBm | 0.5 dBm |

## Telemetry Data Packet Structure

The Telemetry Data Packets include housekeeping data, data important during launchpad idle and buffer for future adjustments.

The following table lists the components of each Telemetry Data Package. 

| Byte position | Use | Size | Value Range | Resolution |
| --- | --- | --- | --- | --- |
| 0 | [COBS](#cobs) | 4 bits | 0 to 10 | / | 
| 0 | [Parity Bit](#parity-bit) | 1 bits | 0 or 1 | / |
| 0 | [Packet Identifier](#packet-identifier) | 1 bit | 1 | / |
| 0 | No Data | 2 bits | / | / |
| 1 | [Subsystem States](#subsystems-states) | 8 bits | 0 to 3 for four subsystems | / |
| 2 | No Data | 1 bit | / | / |
| 2 to 3 | Height (GNSS) | 15 bits | 0 to 6500 m | 0.2 m |
| 4 | GNSS Satellite Count | 4 bits | 0 to 15 | 1 |
| 4 | GNSS HDOP | 4 bits | 0 to 7.5 | 0.5 |
| 5 | Electronics Temperature | 4 bits | 0 °C to 150 °C | 10 °C |
| 5 | Battery Temperature | 4 bits | 0 °C to 150 °C | 10 °C |
| 6 | [Capacitors State](#capacitors-states) | 4 bits | 0 to 3 for two capacitors | / |
| 6 | [Pyros Continuity](#pyros-continuity) | 2 bits | 0 or 1 for two pyro channels | / |
| 6 | [Decoupler Pressure](#decoupler-pressure) | 1 bits | 0 or 1 | / |
| 6 | [Decoupler LDR](#decoupler-ldr) | 1 bits | 0 or 1 | / |
| 7 | No Data | 2 bits | / | / |
| 7 | Battery Voltage | 6 bits | 5 V to 8.15 V | 0.05 V |
| 8 | Battery Current | 3 bits | 0 A to 1.75 A | 0.25 A |
| 8 | Umbilical Current | 3 bits | 0 A to 1.75 A | 0.25 A |
| 8 | [Umbilical State](#umbilical-state) | 1 bit | 0 or 1 | / |
| 8 | [Low Power Mode](#low-power-mode) | 1 bit | 0 or 1 | / |
| 9 | COTS Battery Voltage | 5 bits | 5 V to 11.2 V | 0.2 V |
| 9 | No Data | 3 bits | / | / |
| 10 | No Data | 8 bits | / | / |
| 11 | [End Byte](#end-byte) | 8 bits | `0xEE` | / |
| 12 | RSSI | 8 bits | -127.5 dBm to 0 dBm | 0.5 dBm |

## Frame Components

### COBS

Consistent Overhead Byte Stuffing ([Link](https://en.wikipedia.org/wiki/Consistent_Overhead_Byte_Stuffing)) is used to avoid multiple occurances of the unique end byte `0xEE`.
If there is no occurance of `0xEE` in the data bytes, the COBS value is set to `0x0`.
If there is one or mulitple occurances, the COBS value is set to the byte position of the first occurance.
Then the value of the first occurance (formerly `0xEE`) is set to the byte position of the second occurance and so on.
This is repeated until no `0xEE` except the end byte is left. 
The last occurance will be replaced by the value `0x00` to signal the end of the COBS chain. 

The following table shows an example package with many occurances of `0xEE` being modified using the described method. 
All changes are marked in italic in the modified package.
The modified package only includes one `0xEE` in the end and can easily be converted back to its original shape.
***Note:*** The byte `0x00` which includes the COBS value also includes other data (in this case `0x8`)
| Byte position | `0x00` | `0x01` | `0x02` | `0x03` | `0x04` | `0x05` | `0x06` | `0x07` | `0x08` | `0x09` | `0x0A` | `0x0B` |
| --- | --- | --- | --- | --- | --- | --- | --- | --- | --- | --- | --- | --- |
| Original Package | 80 | 56 | EE | A8 | 9B | EE | 77 | 1F | EE | 0E | EE | EE |
| Modified Package | 8***2*** | 56 | ***05*** | A8 | 9B | ***08*** | 77 | 1F | ***0A*** | 0E | ***00*** | B6 |

### Parity Bit

The parity bit is chosen in a way that the total count of ones in the packet (including the parity bit) is an even number.

If the total count of ones is an odd number when receiving, a bit flip must have occured during transmission and the packet will not be decoded.

### Packet Identifier

Flight Data Packet: `0`
Telemetry Data Packet: `1`

### End byte

The unique end byte is used to identify the end of each package.
If there are multiple occurances of the end byte, the COBS method is used to encode all except the real end byte.
To avoid having the same end byte and byte 0 (COBS and remaining data), `0xEE` was chosen as the unique end byte.
Since the 4 COBS bits in byte 0 will never reach values higher than 10 or `0xA`, `0xEE` is guaranteed to be unique.

## Data Components

### Flight Events

The flight events are described in the [Operations Cheatsheet](/docs/operations_cheatsheet.md#status-events-reference).

### Latitude Longitude
- component size: 52 bits (26 bits each for latitude and longitude)
- value range: -90 ° to 90 ° (latitude) and -180 ° to 180 ° (longitude)
- resolution: 29.9 cm (latitude) and 37.9 cm (longitude)

Latitude and Longitude are stored in two seperate 28 bit integers. 
The resolutions can be calculated using the following formula: <br> 
$\Delta x = 2 \cdot \pi \cdot R \cdot \frac{\Delta \varphi}{360 °} \cdot \frac{1}{2^{26}}$ <br>
$R$ is the radius of the circle under analysis.
When calculating the resolution along the latitude, $R$ equals the Earth's radius of 6731 km.
When calculating the resolution along the longitude, $R$ is depending on the latitude: $R = cos\left(\theta_{lat} \cdot \frac{2 \pi}{360 °}\right)$.
Gießen is located at a latitude $\theta_{lat} = 50.58 °$ which leads to $R = 4045.6$ km. <br>
$\Delta \varphi$ is the angular range and equals 180 ° for latitude and 360 ° for longitude. <br>
Thus the achievable resolution is $\Delta x \approx 29.9$ cm for latitude and $\Delta x \approx 37.9$ cm for longitude.

### Subsystems States

Each of the four subsystems has four possible states:
`0`: Not connected
`1`: Connected but not operational
`2`: Connected and partly operational
`3`: Connected and operational

### Capacitors States

> Voltage levels not yet defined

Each of the two capacitors of the flight control subsystem has four possible voltage levels:
`0`: 
`1`: 
`2`: 
`3`: 

### Pyros Continuity

Each of the two pyro channel has a continuity measurement:
`0`: No continuity
`1`: Continuity

### Decoupler Pressure

`0`: Not enough pressure for operation
`1`: Enough pressure for operation

### Decoupler LDR

`0`: No decoupling detected
`1`: Decoupling detected

### Umbilical State

`0`: Umbilical connection not detected
`1`: Umbilical connection detected

### Low Power Mode

`0`: Low power mode deactivated
`1`: Low power mode activated

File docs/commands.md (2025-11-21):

# Radio command reference for the ASCENT II telemetry system

## General

The command input can be in either lower or upper case letters.
Upper case letters will be converted to lower case letters before transmission.

## Commands

### Ping

**'p'**: Requests data packet from flight computer.

### Main parachute height adjustment

Sets the altitude for the ejection of the main parachute.

**'a'**: 50 m <br>
**'b'**: 100 m <br>
**'c'**: 150 m <br>
**'d'**: 200 m

### Low power mode

Activating the low power mode deactivates most of the onboard LEDs and has potentially more features in the future.

**'l'**: activates the low power mode <br>
**'m'**: deactivates the low power mode

### Flight mode

Activating the flight mode arms the rocket and activates the continous data transmission

**'f'**: activates the flight mode <br>
**'g'**: deactivates the flight mode

### Drogue Parachute Ejection

**'q'**: ejects the drogue parachute immediately

### Main Parachute Ejection

**'r'**: ejects the main parachute immediately

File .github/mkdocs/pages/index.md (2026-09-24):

# ASCENT Telemetry Firmware Reference

API documentation for the onboard and ground-station firmware of the [ASCENT Rocket Telemetry System](https://github.com/Spaceflight-Rocketry-Giessen-e-V/Telemetry), including its [Dynamic Packet Codec Library](https://github.com/Spaceflight-Rocketry-Giessen-e-V/Telemetry/tree/main/libraries/DynamicPacketCodec) and [Radiocrafts RC17xxHP-RC232 Radio Module Library](https://github.com/Spaceflight-Rocketry-Giessen-e-V/Telemetry/tree/main/libraries/Radiocrafts_RC17xxHP_RC232).

## Firmware Documentation

- [Onboard Firmware](onboard/group__onboard.md)  
  Functions, classes, and source file documentation for the rocket onboard telemetry firmware.

- [Groundstation Firmware](groundstation/group__groundstation.md)  
  Functions, classes, and source-file documentation for the groundstation telemetry firmware.

## Library Documentation

- [DynamicPacketCodec](packet/annotated.md)  
Library for dynamically encoding and decoding data packets and handling the packet framing.

- [Radiocrafts RC17xxHP-RC232](radiocrafts/annotated.md)  
Library for configuring and using Radiocrafts RC17xxHP-RC232 radio modules.

## About This Documentation

The API reference is generated by [MkDoxy](https://github.com/JakubAndrysek/MkDoxy) from C/C++ header and source files documented with [Doxygen](https://www.doxygen.nl/)-style comments. The website is built with [MkDocs](https://www.mkdocs.org/) and the [Material for MkDocs](https://squidfunk.github.io/mkdocs-material/) theme.

For hardware files, manuals, and project information, visit the [Telemetry System Repository](https://github.com/Spaceflight-Rocketry-Giessen-e-V/Telemetry).

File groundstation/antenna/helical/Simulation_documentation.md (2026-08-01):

# Antenna Simulation with openEMS

## What is [openEMS](https://github.com/thliebig/openEMS-Project)
openEMS is an open source electromagnetic field solver which utilizes the **FDTD** method. **FDTD** stands for **Finite-difference time-domain** and is a way to discretize the problem and enables us to solve it via the help of computers. 

Antenna simulation is just one of the use cases for the solver. Check out the repository to get a better look at what it can do, and leave a star for the [repository](https://github.com/thliebig/openEMS-Project) to support the amazing work of Thorsten Liebig and the contributors.

## Why simulating
You could ask yourself why simulating and not just using an online tool, buying an already made antenna or trusting a paper/documentation.

With the **right** simulation you have full control over the system. You can change the parameters and see whether the rest of the system will work with the antenna, or whether there are performance degrading effects that need to be mitigated or worked around. An online calculator gives you one number from a closed formula — it cannot tell you what the reflector, the feed or the mounting structure will do to it.

With buying you get a working system but you lose the effect of learning and getting to know the system you are building. You also get the antenna somebody else optimised, for their frequency and their mounting situation, not yours.

With following a paper it is highly encouraged to not blindly trust it, without any form of proof that it is accurate. Rebuilding the geometry in a solver is a kind of proof: if the simulation and the paper agree, the design can be used. The best thing is to always validate what you have done against an outside source.

So the why is simple: simulating is the only one of these options that lets you ask "what happens if I change this?" and get an answer before anything is built. It costs an evening on a laptop instead of a part, a solder joint and a measurement session.

## To run the Simulation

Since the simulation is based on the Octave implementation of openEMS, we need to install **Octave** and **openEMS**.

Octave
-----
Go to the [Octave Wiki](https://wiki.octave.org/Category:Installation) or to the [download page](https://octave.org/download) for the Windows installation.

### Arch

```
pacman -S octave
```
### Windows
On the download page get the version that fits your system.

openEMS
-
Follow the guide [here](https://docs.openems.de/install/clone-build-install.html). Note that the docs tell macOS users to follow a dedicated tutorial — that one is currently broken, so install via the guide above instead.

## The antenna
The antenna is an axial-mode RHCP *(right-hand circular polarisation)* helix antenna for a frequency of $f=869.525\,\mathrm{MHz}$, with the following specifications
($\lambda_0 = c_0/f_0 = 344.78\,\mathrm{mm}$, all dimensions in mm as in the script):

## Setting up the simulation
The simulation we have is separated into 4 parts:
- build up the geometry
- simulate the antenna
- post-process the produced data
- display the data

In our code this is handled by these 4 use cases:

```matlab
disp('  [1] Full run       -- build, simulate, post-process');
disp(sprintf('  [2] Post-proc only -- re-use existing %s/ results', aux_dir_name));
disp('  [3] Geometry check -- open AppCSXCAD, then stop');
disp('  [4] Preview + run  -- geometry check first, then simulate');
```
A **Full run** has to be done to generate the data [2] re-uses. [3] and [4] build the geometry
themselves and need nothing beforehand.

### Where everything is written
The names are not hard-coded, they are derived from the script file at the top of it:

```matlab
[script_dir, script_name] = fileparts(mfilename('fullpath'));
aux_dir_name = 'Simulation_auxiliary_files';
Sim_Path = fullfile(script_dir, aux_dir_name);
Sim_CSX  = [script_name '.xml'];
```

So `Helical_Antenna.m` writes its geometry to `Simulation_auxiliary_files/Helical_Antenna.xml`, and
everything the run produces — field dumps, port data, figures, the VTK — lands in that same
`Simulation_auxiliary_files/` folder next to the script. Rename or copy the script and the XML
follows the new name, which keeps two variants from overwriting each other's geometry.
### Frequency and excitation
```matlab
f0 = 869.525e6;
fc = 100e6;
FDTD = InitFDTD('NrTS', 1e6, 'EndCriteria', 1e-5);
FDTD = SetGaussExcite(FDTD, f0, fc);
```

The antenna is not simulated at one frequency. It gets hit once with a short pulse and we watch it
ring down, which gives us the whole band in a single run — the same picture a VNA sweep gives you.

The two numbers set that band. `f0` is the **center**, `fc` is the **half-span** either side:

<div align="center">

| Parameter | Value |
|:---:|:---:|
| `fc` | 100 MHz |
| Excited band | 769.5 … 969.5 MHz |

</div>

**Changing `fc` changes the plot, not the antenna.** A wider span does not make the helix
broadband; it only widens the window you look through. What it does change is how long the run
takes, and it gets more expensive in *both* directions:

- **Smaller `fc` → longer simulation.** A narrow pulse in frequency is a long pulse in time, and
  the solver has to step through all of it. Halving `fc` roughly doubles that part of the run.
- **Larger `fc` → finer mesh.** The cell size is tied to the highest frequency in the pulse, so a
  wider span means smaller cells everywhere, and more of them.

100 MHz sits in the middle: cheap enough to run, wide enough to see the resonance move when a
parameter changes.

### Boundary conditions
```matlab
BC = {'PML_8' 'PML_8' 'PML_8' 'PML_8' 'PML_8' 'PML_8'};
FDTD = SetBoundaryCond(FDTD, BC);
```

Six faces, six absorbers. A **PML** swallows outgoing waves instead of reflecting them, so the box
behaves like open space.

`PML_8` is 8 cells thick, and those cells are **taken out of the box, not added around it** — so
the air gap has to pay for the PML *and* still leave real air between it and the antenna:

```matlab
air_gap = 0.75 * lambda0;   % 258.6 mm = 79.6 mm PML + 179 mm real air (0.52 lambda)
```

Keep the antenna at least λ/4 clear of the PML. Too close and it absorbs near-field energy that
should have stayed put, and `Zin` comes out wrong.

### The mesh
Two stages: fine lines where the geometry is, then graded out to coarse everywhere else.

```matlab
mesh.x = SmoothMeshLines([-Helix.radius 0 Helix.radius], Helix.mesh_res);  % 1.5 mm
mesh_x_tmp = [mesh.x, -gnd_size/2, gnd_size/2, -sim_r, sim_r];
mesh.x = AutoSmoothMeshLines(mesh_x_tmp, max_res, grade);                  % out to 10 mm
```

`SmoothMeshLines` puts 1.5 mm lines across the helix, `AutoSmoothMeshLines` grows them out to
`max_res` with no cell more than `grade = 1.2`× its neighbour. `max_res` is λ/30 at the *highest*
excited frequency, not at `f0` — `c0/(f0+fc)/30` = 309 mm / 30 → 10 mm. The ramp has to be
gradual — an abrupt size jump reflects waves off the grid itself.

Use `AutoSmoothMeshLines` for that second stage, not `SmoothMeshLines`: the plain version can
silently return a mesh that misses the grading ratio you asked for.

**The smallest cell sets the runtime**, because it caps the timestep. Halving
`mesh_res` costs 8× the cells *and* half the timestep — about 16× the run. Here: 167 × 167 × 396 =
**11.0 M cells** at 2.86 ps.

### Geometry: helix, ground plane, feed
**The helix** — the parametric equation of a coil, sampled into points and given a thickness:

```matlab
t = linspace(0, 2*pi*Helix.turns, pts*ceil(Helix.turns));
coil_x = Helix.radius * cos(t);
coil_y = Helix.radius * sin(t);
coil_z = (t/(2*pi)) * Helix.pitch + feed.height;   % rises one pitch per turn
CSX = AddWire(CSX, 'helix', 0, p, Helix.wire_rad);
```

`AddWire` gives the conductor a real 3 mm radius. `AddCurve` looks like the same thing but is a
zero-thickness filament, and it ignores a `'Radius'` argument without warning.

**The ground plane** — a 64-sided polygon standing in for a 400 mm disc:

```matlab
theta_gnd = (0:num_gnd_pts-1) * 2*pi/num_gnd_pts;   % NOT linspace(0, 2*pi, N)
```

`linspace(0, 2*pi, N)` would include both 0 and 2π — the same point twice — giving the polygon a
zero-length edge.

**The feed** — a lumped port up the 15 mm gap between ground plane and helix:

```matlab
[CSX, port] = AddLumpedPort(CSX, 5, 1, feed.R, start, stop, [0 0 1], true);
```

`feed.R = 140` because that is roughly what an axial-mode helix presents (Kraus: $140\,C/\lambda$).
It is only the reference that S11 is measured against, but a realistic one keeps the port matched so
the pulse goes into the antenna instead of bouncing. 50 Ω is compared later, in post-processing.

### NF2FF box
```matlab
start_nf = [mesh.x(11) mesh.y(11) mesh.z(11)];
stop_nf  = [mesh.x(end-10) mesh.y(end-10) mesh.z(end-10)];
```

The solver only knows the inside of the box, but a radiation pattern lives infinitely far away.
Recording the fields on a closed surface lets everything outside be computed from them — that
surface is the NF2FF box.

The indices are the point: `PML_8` uses 8 cells, so `11` / `end-10` keeps the box in real air, a
couple of cells clear of it (±359 mm inside a ±459 mm box). Fields inside the PML are being damped
on purpose, and feeding those to the transform gives a nonsense pattern.

## Running it
The menu at the top of the script sets three flags — `run_fdtd`, `show_geometry`, `do_postproc` —
and everything below just checks them:

| Mode | Does | Use it when |
|:---:|:---|:---|
| **1** Full run | build → simulate → post-process | the normal case |
| **2** Post-proc only | re-use `Simulation_auxiliary_files/` | replotting, tweaking a figure |
| **3** Geometry check | open AppCSXCAD, then stop | after changing dimensions |
| **4** Preview + run | look first, then simulate | changed geometry, ready to commit |

**Run mode 3 after every geometry change.** AppCSXCAD draws what the solver will actually see, so a
helix wound the wrong way or a feed that misses the coil is obvious in seconds instead of an hour.

### Threads
Modes 1 and 4 ask for a thread count before they start; modes 2 and 3 never solve, so they do not
ask. Press Enter for the default of 14, type a number, or type `auto`:

```matlab
RunOpenEMS(Sim_Path, Sim_CSX, ['--engine=multithreaded' thread_opt ' --dump-statistics']);
```

| Answer | `thread_opt` | Effect |
|:---|:---|:---|
| *(Enter)* | `--numThreads=14` | the default: 16 cores, two left for the desktop |
| `8` | `--numThreads=8` | fixed count, rejected if not a positive integer |
| `auto` | *(omitted)* | openEMS tunes it itself |

`auto` is not "use all cores". Leaving `--numThreads` off puts the multithreaded engine into a
self-tuning mode: it starts at **one** thread and adds another every statistics interval until the
measured speed stops improving, then backs off one and keeps that. It reports the result as
*"Multithreaded Engine: Best performance found using N threads."* Intervals are about 4 s here, so
the ramp costs roughly a minute — worth it if you do not know the right number, wasteful if you do.

Asking for more threads than you have only warns; openEMS clamps to `hardware_concurrency()` itself.

About **7 minutes** at 14 threads (11.0 M cells, 13 905 timesteps, 425 s at 3.6·10⁸ cells/s) on a AMD Ryzend 7800x3d. The
run stopped on `EndCriteria`, not on the 10⁶ timestep cap — energy was down to 5·10⁻¹⁸ from a
5·10⁻¹³ peak. Note mode 1 wipes `Simulation_auxiliary_files/` first, so keep a copy if you want to
compare two runs.

## Reading the results
Post-processing is the second half of the script. `00_overview.png` has three panels: the first two
ask whether power gets *into* the antenna, the last where it goes once it is in. The 3D pattern is
not plotted in Octave at all, it goes to Paraview as a VTK. All numbers below are from the run in
`Simulation_auxiliary_files/`, at $f_0 = 869.525$ MHz.

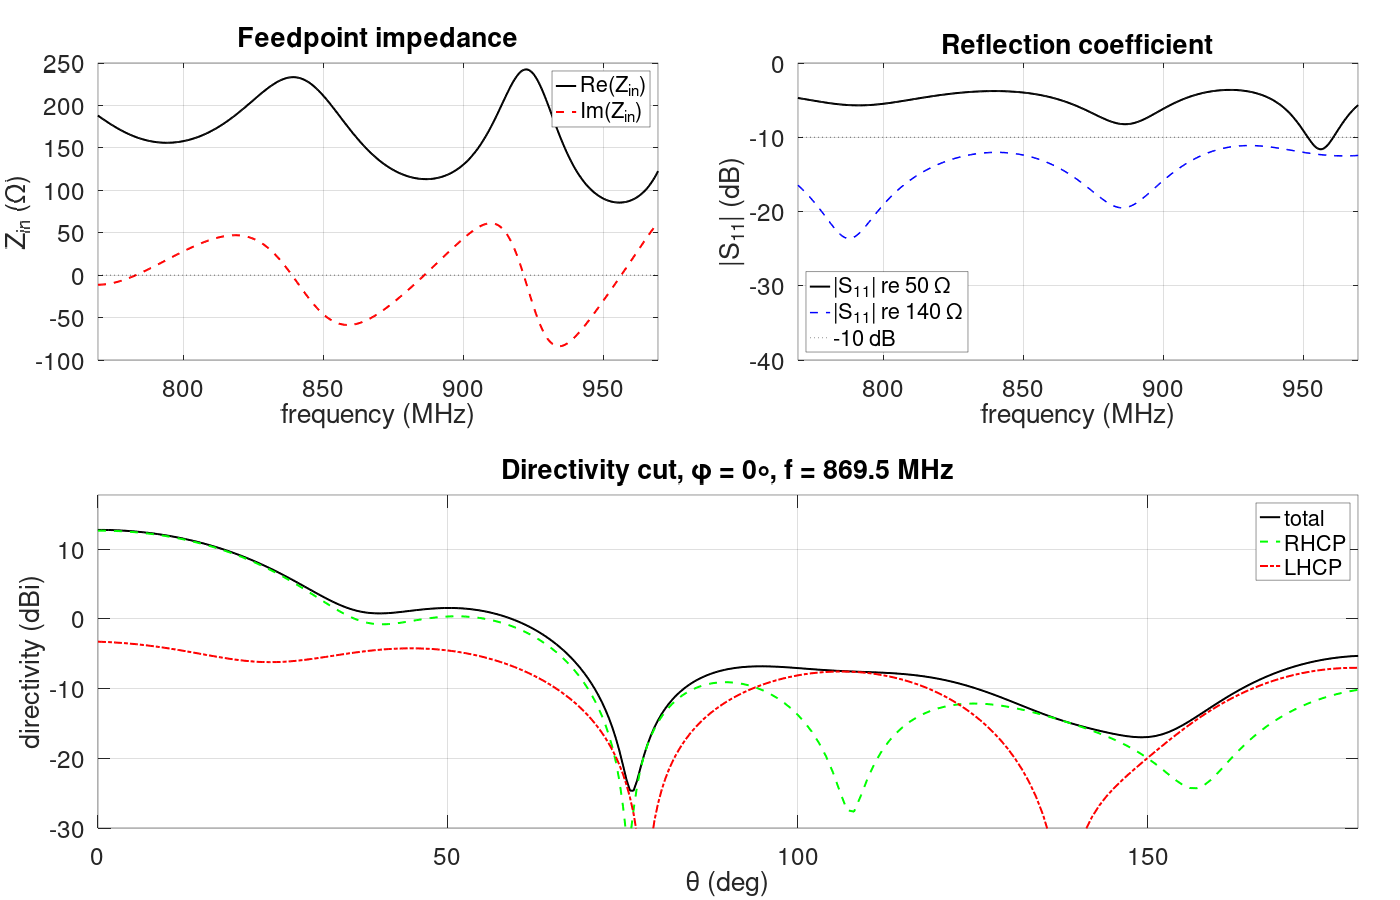
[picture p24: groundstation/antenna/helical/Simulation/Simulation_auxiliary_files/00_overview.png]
All three result panels in one figure


Every panel is also written out on its own, and the whole figure is saved as `results.ofig` — reopen
that with `openfig()` and the plots are still live and zoomable, which a PNG is not.

All of them inside `Simulation/Simulation_auxiliary_files/`:

| File | Panel |
|:---|:---|
| `00_overview.png` | all three together |
| `01_impedance.png` | $Z_\mathrm{in}$ vs frequency |
| `02_s11.png` | S11 against 50 Ω and 140 Ω |
| `03_polarization.png` | directivity vs $\theta$, RHCP vs LHCP |
| `3D_Pattern.vtk` | the full pattern, for Paraview |

### Impedance and S11
`calcPort` reads the recorded port voltage and current; one impedance then gives two S11 curves:

```matlab
Zin = port.uf.tot ./ port.if.tot;
s11      = (Zin - Z0)     ./ (Zin + Z0);      % Z0 = 50, the real coax
s11_feed = (Zin - feed.R) ./ (Zin + feed.R);  % 140, the port reference
```

| | |
|:---:|:---:|
| $Z_\mathrm{in}(f_0)$ | 136.5 − j45.5 Ω |
| S11 against 50 Ω | −5.9 dB |
| S11 against 140 Ω | −15.8 dB |

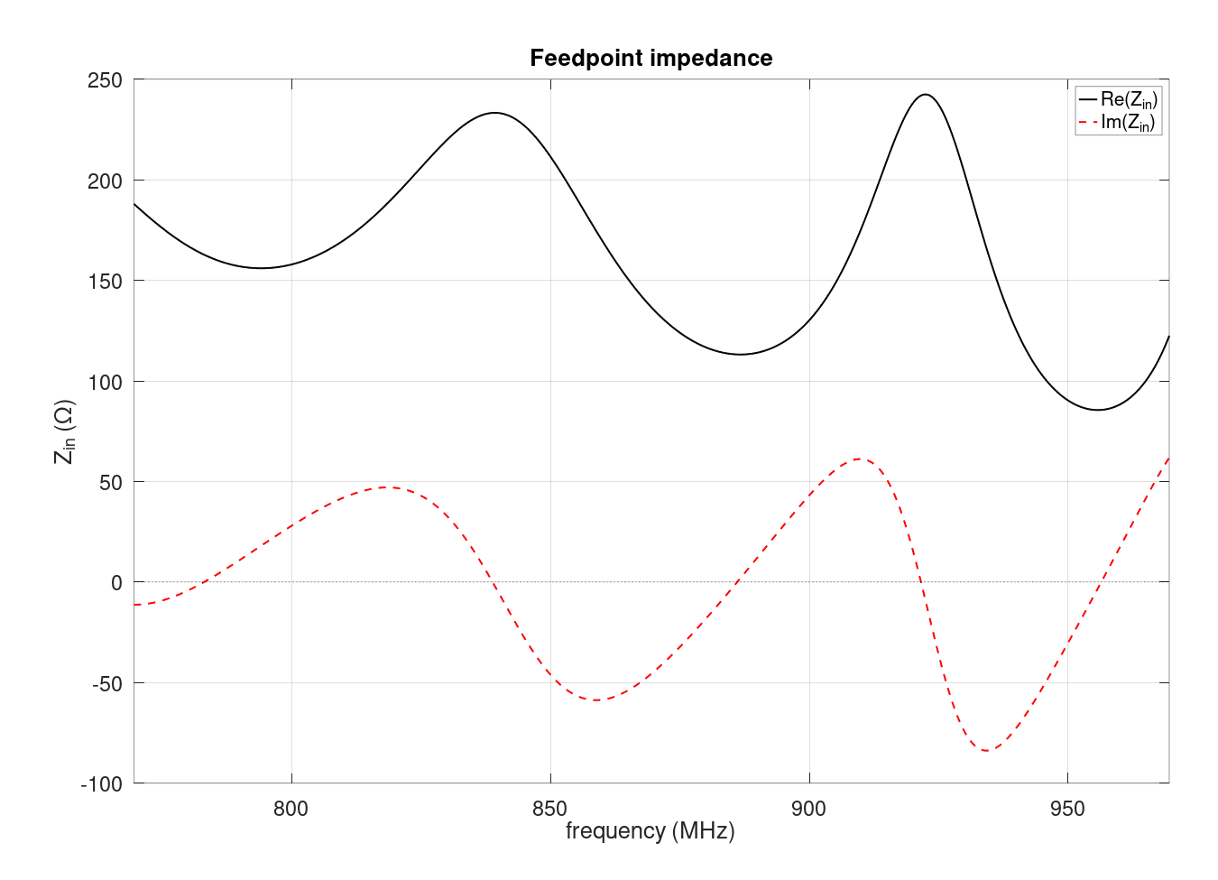
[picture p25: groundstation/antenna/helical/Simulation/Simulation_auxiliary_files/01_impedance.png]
Real and imaginary part of the input impedance over the excited band


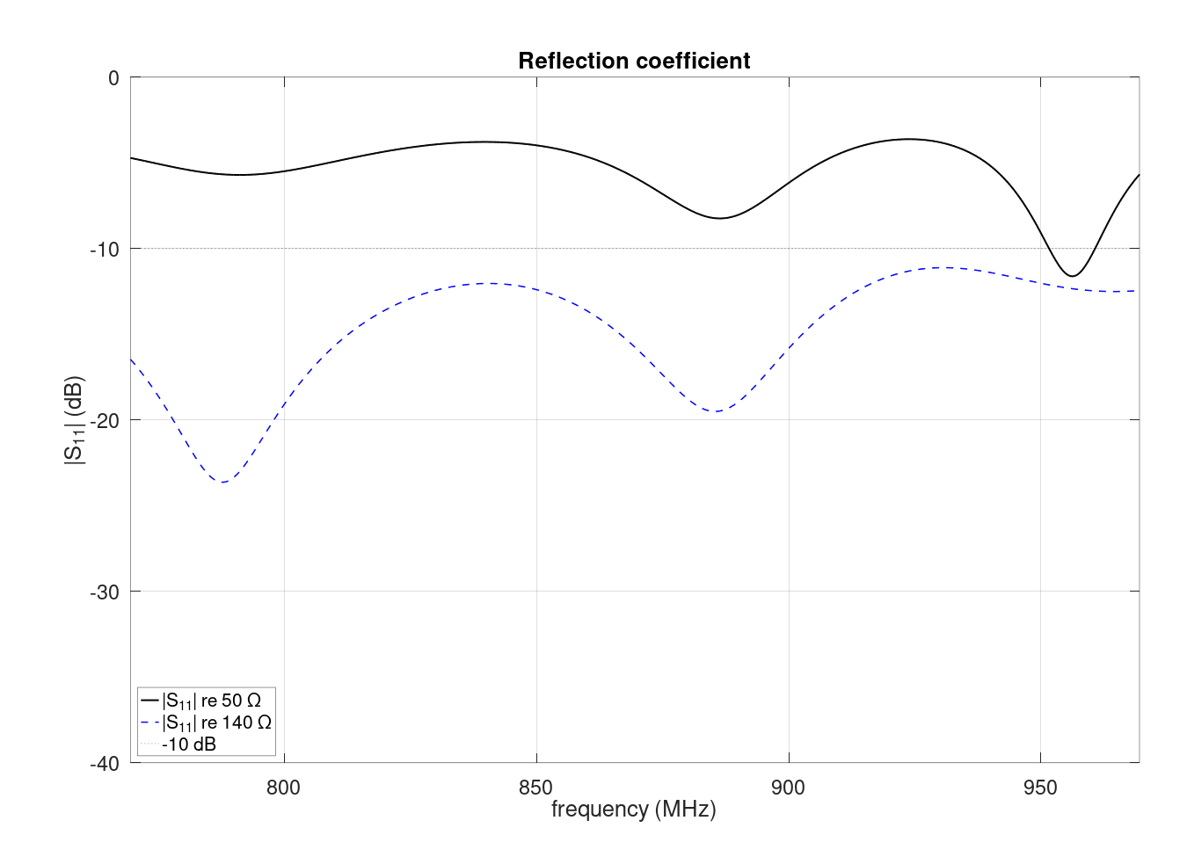
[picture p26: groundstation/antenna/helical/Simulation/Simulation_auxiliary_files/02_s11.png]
S11 referenced to 50 ohm and to 140 ohm


137 Ω is within a few percent of the 140 Ω the design assumed, so the helix is behaving as it
should. Nothing changes between the two curves except the reference: the mismatch is not a flaw in
the antenna, it is 137 Ω meeting a 50 Ω cable. The 140 Ω curve is what you would measure after
fitting a matching network.

### Directivity, beamwidth and polarization
`CalcNF2FF` turns the recorded surface fields into a pattern; the HPBW block then walks outwards
from the peak to find the −3 dB point.

| | Simulated | Kraus |
|:---:|:---:|:---:|
| $D_\mathrm{max}$ | 12.8 dBi | 13.2 dBi |
| HPBW | 37° | 44° |

The beam points along the axis ($\theta = 0$),that is what "axial mode" means — and lands just
under the Kraus estimate, which is known to run optimistic. Straight backwards ($\theta = 180°$) is
−5.3 dBi, 18 dB below the main beam; nothing in the back hemisphere exceeds −4.8 dBi.

The bottom panel splits the pattern into the two circular polarizations:

```matlab
directivity_CPRH = abs(nf2ff.E_cprh{1}).^2 ./ max(nf2ff.E_norm{1}(:)).^2 * nf2ff.Dmax;
```

| At boresight | |
|:---:|:---:|
| RHCP | 12.7 dBi |
| LHCP | −3.3 dBi |
| Axial ratio | 2.8 dB |

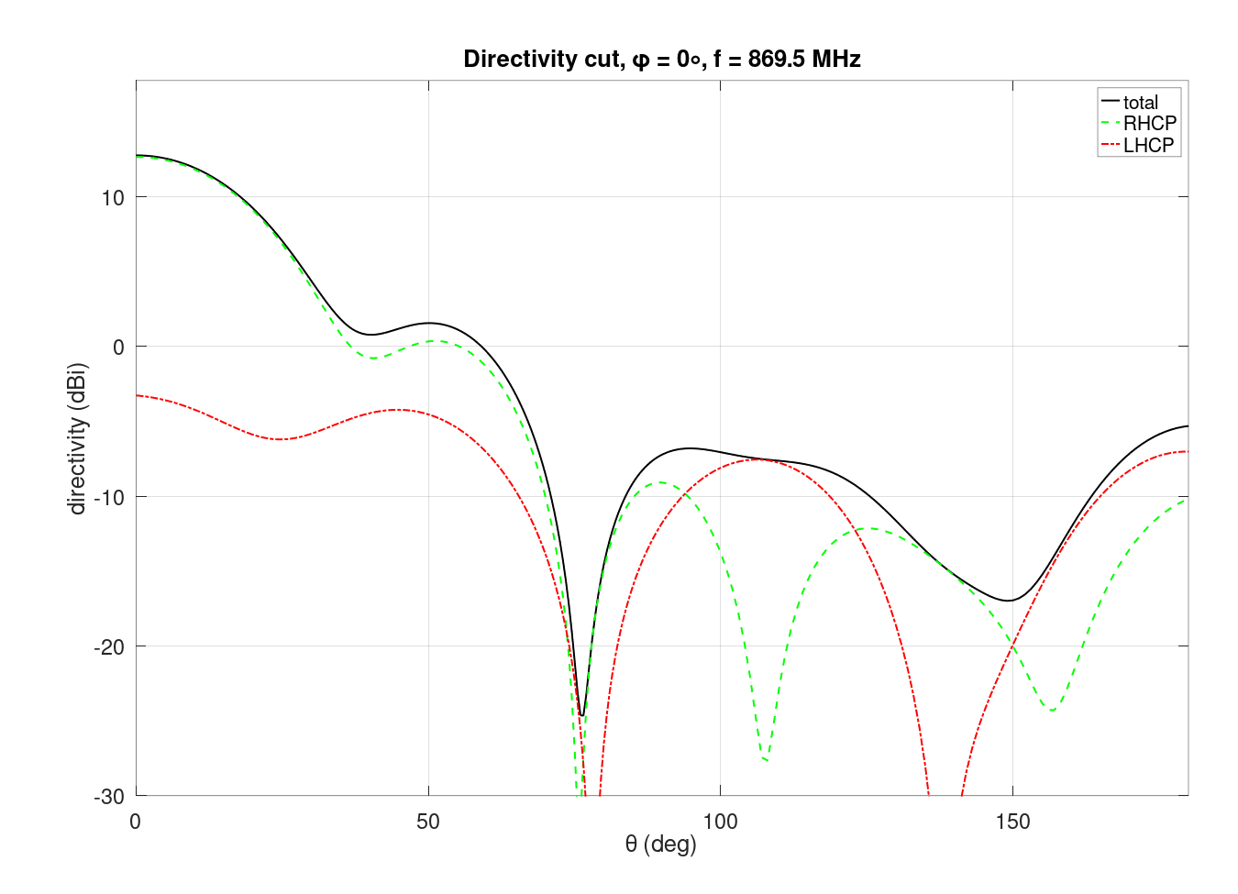
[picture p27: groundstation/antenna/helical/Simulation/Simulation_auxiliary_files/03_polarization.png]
Directivity vs theta, total and split into RHCP and LHCP


RHCP sits 16 dB above LHCP, which is the sign the helix is wound and fed correctly. If those two
curves ever land on top of each other the radiation is linear and something is wrong.

### Realized gain
Directivity ignores the power that never got in. Realized gain does not, and it is the number for a
link budget:

```matlab
ML_50   = 10*log10(1 - abs(s11(i0))^2);
ML_feed = 10*log10(1 - abs(s11_feed(i0))^2);
```

| | Mismatch loss | Realized gain |
|:---:|:---:|:---:|
| Straight into 50 Ω coax | −1.3 dB | **11.5 dBi** |
| With a 50 → 140 Ω match | −0.1 dB | **12.7 dBi** |

### Paraview
The 3D pattern is dumped once, in linear directivity — surface radius and the `gain` scalar are the
same quantity:

```matlab
DumpFF2VTK([Sim_Path '/3D_Pattern.vtk'], directivity, thetaRange, phiRange, 'scale', 1e-3);
```

Colour by `gain`, no Calculator needed. Peak equals $D_\mathrm{max}$.

## Limitations and sanity checks
What the model leaves out:

- **Conductor loss** — `AddMetal` is PEC, so every gain figure is optimistic by a few tenths of a dB.
- **Feed cable, mast, mounting** — nothing in the near field but the antenna itself.

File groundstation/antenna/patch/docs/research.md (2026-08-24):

# Patch Antenna — 869.525 MHz RHCP Ground Station

Design notes for the SPROG telemetry ground-station patch antenna: what it is, why it is
built this way, and what has to be verified on the physical boards. Synthesised from the
openEMS simulations in this repo, multi-source web research, and the review paper
*Yahya et al., "LoRa Microstrip Patch Antenna: A comprehensive review," Alexandria
Engineering Journal 103 (2024) 197–221* (doi:10.1016/j.aej.2024.06.045).

> **The design.** One flat 2-layer **NP-140F (FR-4-class)** PCB, **160×160 mm**. RHCP comes
> from a **single-feed corner-truncated** patch (two diagonally-opposite corners chamfered),
> fed by **one** inset microstrip to **one** edge-launch SMA — no coupler, no termination
> resistor, ~€25–45 for 5. The antenna is a **fixed, wide-beam RHCP backup** behind the
> tracked helical; the 10 km link closes with large margin, so coverage and robust CP matter
> more than gain.
>
> **Geometry (locked):** patch side **W = 82.5 mm**, corner truncation **Δ = 8.25 mm**, feed
> inset **5.8 mm**, ground plane **160 mm** — these are the `config.py` synthesis seeds.
>
> **Simulated performance** (`fab/results.json`): boresight **AR 1.04 dB**, AR ≤ 3 dB over a
> **152° beam** and a **6.5 MHz** band, worst AR **1.66 dB** across the ±45° coverage cone,
> **S11 −12.6 dB**, directivity **6.6 dBi**, **η_rad 29 %** / η_tot 27 %, realised gain
> **+1.0 dBic** boresight (−1.8 dBic at the 45° cone edge), **RHCP**.

---

## 1. Project context

| Fact | Value |
|---|---|
| Operating frequency | 869.525 MHz (EU 868 ISM; high-power sub-band 869.4–869.65 MHz), λ₀ ≈ 345 mm |
| Polarisation needed | **RHCP** — the rocket carries an onboard **RHCP quadrifilar helix**, so RHCP↔RHCP is a matched pair (0 dB polarisation loss). LHCP would be a deep mismatch. |
| Role of this antenna | A **fixed, wide-beam RHCP** receiver. A separate **tracked high-gain helical** handles the primary link, so this patch *complements* it (wide coverage, robust CP) rather than duplicating it with a high-gain pencil beam. |
| Why CP at all | A spinning/tumbling vehicle rotates its onboard antenna; matched CP avoids the deep polarisation fades that linear↔linear suffers. With an RHCP rocket, same-sense CP is the only correct choice. |

> ⚠️ **Sense matters most.** RHCP↔RHCP = matched; RHCP↔LHCP = 20+ dB loss. The onboard QFH is
> **RHCP (confirmed by the team)** and this patch is **RHCP** via the bottom-left + top-right
> truncated diagonal, so the pair is matched. The ground helical must be RHCP too: the patch's
> sense is set by the CP perturbation and is trivial to flip in design, whereas the **helix's
> sense is fixed by its winding** — treat the helix as the reference and match everything else
> to it. A mirrored patch layout yields a perfect *LHCP* antenna, deaf to the rocket.

---

## 2. Microstrip patch fundamentals

- A patch resonates when its length ≈ λ/2 in the substrate; higher permittivity εr shrinks it
  (≈ 1/√εr), lower loss raises efficiency. FR-4 class here: εr ≈ 4.15, tanδ ≈ 0.014,
  h = 1.6 mm → patch ≈ 83 mm. Air (εr ≈ 1) would need ≈ 165 mm.
- Feed options: inset microstrip, coaxial **probe**, proximity-coupled, aperture-coupled. This
  build uses an etched inset microstrip on the −y edge; the model feeds it at that inset point
  ([../src/model.py](../src/model.py)). All RF geometry is etched, so the antenna is
  reproducible by etch alone — no probe, no spacer, no extra layer.
- The **ground plane** separates two worlds: the radiating side (above) and the
  feed/electronics side (below). Keep all coax/connectors/radio **below** it.

### Circular polarisation — three ways to make it
| Method | AR bandwidth / robustness | Efficiency | Note |
|---|---|---|---|
| **Single-feed corner truncation** (**CHOSEN**) | ~0.5–2 % on thin substrate; tight on 1.6 mm FR-4 | **high — no loss network** | CP from one mode-split; AR is εr/fab-sensitive but tunable with a known εr. All accepted power goes to the patch. |
| Single-feed slot/U-slot variants | ~2–7 % | high | lateral AR improvement only |
| Dual-feed 90° hybrid (branch-line coupler) | ~6–30 %+, tolerance-proof | **low** | quadrature enforced by copper, but the coupler's isolated port terminates into a resistor that absorbs the patch's feed-point mismatch — a structural efficiency sink a good *input* match hides. Robust CP, poor realised gain. |
| Sequential rotation (array) | >15 %, excellent | high | cross-pol cancels by geometry; needs many elements + a feed network |

**Why single-feed.** The coupler buys εr-robust CP, but its isolated-port resistor is a
structural sink: it swallows the patch mismatch instead of radiating it, costing roughly an
order of magnitude in realised gain on the same board. Single-feed has no such sink — every
watt accepted goes to the patch — at the price of an εr/fab-sensitive AR. That price is
payable here because the AR ≤ 3 dB window width ∝ 1/Q and:

1. NP-140F's εr is datasheet-specified (±0.1), so resonance lands predictably (§5);
2. FR-4-class loss *lowers* Q and therefore *widens* the AR window compared with a low-loss
   laminate;
3. the optimiser centres the **AR null** (not the S11 dip) on f_target (§3);
4. a thicker substrate widens AR further, if a future revision wants the margin (§6).

The residual risk — a narrow AR band against εr and thermal drift — is handled by a per-board
acceptance test rather than by design (§9).

---

## 3. Design rules that govern this patch

### CP centre and impedance match are separate tuning targets
A *matched* patch is not automatically circular at f_target. On this geometry the axial-ratio
null sits **~6–7 MHz below the S11 centroid**, so tuning on the S11 dip lands the CP null
below the channel. Measured by NF2FF on real sim data (same Δ and inset, only W varied):

| W (mm) | AR-null frequency | AR @ 869.525 MHz | S11 centroid |
|---|---|---|---|
| **82.5 (locked)** | **869.0 MHz** | **1.0 dB** ✓ | 875.0 MHz |
| 83.05 | 863.5 MHz | 4.6 dB ✗ | 870.2 MHz |

A 0.55 mm change in W moves the null ~5.5 MHz and takes AR at f_target from ~1 dB to ~4.6 dB.
**Rule: centre the design on the AR null and verify CP on the AR(f) curve, never on the S11
dip.**

### Truncation sets the mode split; W centres it
Single-feed CP splits the TM10/TM01 modes into an equal-amplitude 90° pair at f₀. The classic
design rules are **truncation area dS/S ≈ 1/(2·Q0)** and **AR bandwidth ≈ 1/(√2·Q0)** — both
say the same thing: low Q buys forgiving CP. Δ and W are coupled (Δ sets the split, W centres
it), so they have to be tuned together. Δ = 8.25 mm ≈ 0.10·W sits at the deepest null for this
1.6 mm stackup; enlarging Δ over-splits the modes and destroys CP, so the AR band cannot be
widened by truncation alone — only by lowering Q (thicker substrate or an air gap).

Measured on a (W × Δ) drift-margin sweep (`tests/tool_trunc_bw_sweep.py`, W fixed at 82.5 mm):
boresight AR_min climbs monotonically **0.41 → 2.83 → 5.44 → 7.55 dB** for Δ = **8.25 → 9.5 →
11 → 12.75 mm**. At converged fidelity Δ = 8.25 / 8.5 / 8.6 are indistinguishable (6.5–6.7 MHz
band, ~3 MHz of drift margin), so apparent band differences seen at coarse fidelity do not
survive convergence. Δ = 8.25 mm stands as the optimum for this stackup.

### Gain is efficiency-limited, not aperture-limited
Directivity (6.6 dBi) is already at what a single patch gives. The antenna loses ~5 dB to
dielectric loss and mismatch, so the gain levers are efficiency, not board size:

| Lever | Δ realised gain | Cost / tradeoff |
|---|---|---|
| **3.2 mm substrate** (1.6→3.2 mm) | **+1.5–2 dB** (+ wider AR) | ~free as stock thickness, re-tune only — best bang/buck |
| Air/foam gap (~10–25 mm) | **+3–4 dB** (η → ~85 %) | a 3-D assembly instead of one etched board |
| Stacked parasitic patch | +1–2 dB (+ BW) | adds a layer/spacer |
| Lower-loss laminate (Rogers) | +3–4 dB | over budget |
| Soldermask keep-out over the patch | +0.1–0.3 dB | free; makes the build match the bare-copper sim (already in `kicad_export`) |
| 2 oz copper | +0.1–0.2 dB | cheap insurance for feed and edges |
| Board 160→200 mm | only ~+0.5 dB directivity | *narrows the beam* — trades coverage (§4) |
| 2×2 array | +6 dB | needs >250 mm plus a feed network — breaks the size/coverage budget |

**The asymmetry that decides everything here:** every *directivity* lever (bigger board,
stacking, arrays) narrows the beam and fights the wide-beam role, while every *efficiency*
lever (thickness, air gap, laminate) raises gain *without* narrowing it. Prefer efficiency.
Any stackup change makes a re-optimise of W/Δ/inset mandatory.

### Optimiser and convergence
A **2-D grid (patch side W × corner-truncation Δ) screen plus a full-fidelity confirm**
(`config.py`: `GRID_W_FRAC` × `GRID_TRUNC_MM`, `N_CONFIRM`). W sets resonance, Δ sets the CP
mode-split, and the AR null is only centred on f_target when both are right together — a
sequential coordinate descent cannot navigate that coupling. The worker scans boresight AR
across f_target ± 30 MHz and the cost functions centre `f_ar_null`. Selection uses a
deadband+ramp resonance penalty (`F_RES_*`), the worst AR over f_target ± `AR_MARGIN_MHZ`,
an AR ≤ 3 dB beamwidth reward, a gain floor, and a **radiation-efficiency reward** (`W_EFF`)
so the optimiser keeps designs that actually radiate. The board is locked at 160 mm for
coverage and is not swept.

**Convergence is part of the method, not a formality.** Resonance and match settle quickly,
but the CP null is a razor feature that is time-step-limited far longer: it only stops moving
above ~250k FDTD time steps, which is why the screen runs at `NrTS_screen = 150000` and the
deliverable run at `NrTS_final = 350000`. Judge AR only at full fidelity, and confirm any
headline AR figure on a time-step ladder rather than a single run. The same applies to mesh:
under-meshed truncated corners report *optimistic* AR.

The ladder on the locked geometry: boresight AR **0.45 dB @ 150k → 1.04 @ 250k → 1.04 @ 350k**,
AR ≤ 3 dB band **7.9 → 6.6 → 6.5 MHz**. 250k and 350k agree, so the deliverable run
(`fab/results.json`) is converged; coarser runs read optimistically on both figures. Finer
chamfer meshing was not needed — the null and band stop moving on the time-step axis alone.

### Verification procedure
1. Size W for the substrate εr so resonance lands near the channel.
2. Set Δ from the Q estimate (dS/S ≈ 1/(2·Q0)); truncate the diagonal that yields **RHCP**
   (bottom-left + top-right → RHCP at +z).
3. Place the inset for a 50 Ω match, then re-check — match and CP centre move independently.
4. Centre the **AR null** on f_target on a fine frequency grid (a coarse grid or heavy
   smoothing hides a few-MHz null entirely).
5. **Sense-check RHCP from the far field** (E_R vs E_L). The wrong diagonal gives LHCP and
   ~20 dB loss against the rocket's RHCP helix. Verify before fabrication.
6. Check AR over the **coverage cone**, not just boresight — the rocket moves across the sky.
7. Confirm the run is converged (time-step ladder, mesh at the chamfers).

`tests/stage0_dipole_calibration.py` is the permanent calibration gate for the far-field
chain: a lossless half-wave dipole must come back at η ≈ 100 % and Dmax 2.19 dBi against the
textbook 2.15 dBi. Run it whenever absolute directivity or efficiency numbers look off.

---

## 4. Ground plane, beamwidth and board size

**Ground-plane size has sharply diminishing returns.** From a ground-plane sweep on this patch
family:

| GP edge | board/λ₀ | directivity |
|---|---|---|
| 150 mm | 0.43 | 6.4 dBi |
| 250 mm | 0.72 | 7.2 dBi |
| 300 mm | 0.87 | 7.4 dBi |
| 350 mm | 1.01 | 7.6 dBi |
| 375 mm | 1.09 | 7.6 dBi |
| 400 mm | 1.16 | 7.4 dBi (edge-diffraction ripple) |

About +1 dB across the whole 150→375 mm range, most of it reached by ~250 mm, then ripple past
~1 λ₀. A patch ground only needs ~0.5–1 λ for a clean pattern, and realised *gain* is set by
efficiency (§3), not ground size. **A bigger board is cost and a narrower beam, not gain.**

**Smaller ground = wider beam, and that is what this antenna wants.** A beamwidth-vs-ground
sweep shows the AR ≤ 3 dB coverage beam widening as the ground shrinks:

| GP edge | AR ≤ 3 dB beamwidth |
|---|---|
| 160 mm | 52° |
| 170 mm | 40° |
| 180 mm | 36° |
| 190 mm | 28° |

So **160 mm is a deliberate coverage choice**, not a manufacturing floor: the patch itself
(~83 mm plus feed and margin) would fit on much less. The board is square and centred on the
patch, leaving all four corners clear for 4× M3. Going to 200 mm buys ~+0.5 dB directivity
while narrowing the beam — only do that when deliberately trading coverage for gain.

---

## 5. Cost and laminate

PCB price is driven by **area** with discrete tier jumps. JLCPCB: ≤100×100 mm hits a ~2 USD
promo tier, and a per-50 cm² surcharge starts above **650 cm²** (≈ a 255 mm square) — so the
**160×160 board (256 cm²) is comfortably in the cheap tier** (~25–45 €/5 incl. ship+VAT to
the EU).

| Board | directivity @1.6 mm | 5× JLCPCB (incl. ship+VAT) | 5× Aisler (EU) |
|---|---|---|---|
| 100×100 | ~5.7 dBi | ~15–25 € | ~54 € |
| 120×120 | ~6.0 dBi | ~25–40 € | ~72 € |
| 150×150 | 6.4 dBi | ~35–55 € | ~104 € |
| **160×160 (CHOSEN)** | **6.6 dBi** | **~25–45 €** | ~115 € |
| 170×170 | ~6.6 dBi | ~45–70 € | ~129 € |
| 375×375 | 7.6 dBi | ~140 € | — |

Within the allowed range, **directivity moves <1 dB while cost goes 2–3×** → pick small. Real
performance comes from the **substrate**, not the size. *Mid-loss "FR-4" grades (S1141,
S1000H) are not low-loss — they are the default stock — so they buy ~0 dB; genuine low-loss
means Rogers / I-Speed / S7-series, which break the budget.*

**Laminate — NP-140F for predictability, not for loss.** The build specifies **Nan Ya NP-140F**
(FR-4-class, Tg 135 °C) rather than generic stock FR-4. The reason is *not* loss: NP-140F's
tanδ ~0.013–0.014 against stock ~0.0155 buys ~0.3–0.5 dB, irrelevant against a 22–30 dB link
margin (exactly the "mid-loss FR-4 ≈ 0 dB" point above). The reason is **εr predictability**: a
resonant patch lands where εr says it will, and NP-140F is datasheet-specified at
**εr 4.0–4.2 (±0.1)**, whereas stock FR-4 is an unspecified ~4.2–4.6 grab-bag (the common stock
part, KingBoard **KB-6164**, measures ~4.6 / 0.0155 @ 1 GHz). Known and tighter εr means
~±10 MHz of batch resonance scatter instead of ~±20 MHz, i.e. boards that hit 869.525 MHz
without per-unit tuning. At equal cost, with the laminate guaranteed if it is specified,
NP-140F is the pick — design εr = 4.15 @ 870 MHz.

> ⚠️ **Confirm the fab actually supplies NP-140F at 160×160.** Cheap tiers stock
> KingBoard/Shengyi (KB-6164-class), so a bare "FR-4" order silently delivers εr ~4.6 and the
> patch lands ~25 MHz low. Get it in writing, and keep the re-tune ready as a fallback.

---

## 6. Upgrade paths (if a future revision wants more)

The built board is 1.6 mm and stays 1.6 mm. If a revision needs more gain or more AR margin,
take the efficiency levers in order — they raise gain *without* narrowing the coverage beam:

1. **3.2 mm substrate** (+1.5–2 dB, and a wider/more drift-tolerant AR window because Q drops).
   Available at PCBWay; JLCPCB caps at 2.0 mm. Requires a full re-tune of W/Δ/inset.
2. **Air/foam gap (~20–25 mm).** Two wins at once: a lossless dielectric takes efficiency to
   ~90–95 % (the ~2.5–3.5 dB now lost as heat radiates instead), and a thick low-ε gap drops Q
   roughly 10×, widening the AR ≤ 3 dB window from a few MHz to ~25–30 MHz — enough to absorb
   fab, εr and thermal drift outright. The costs are real: the patch grows ~2× (εr ≈ 1, ~165 mm
   side), it becomes a 3-D assembly whose gap height must be held rigidly (the gap sets f₀, Q,
   AR *and* match), and a straight probe through that gap is strongly inductive, so it needs an
   L-probe or a series capacitance to cancel the reactance.
3. Stacked parasitic patch (+1–2 dB) or a superstrate, if aperture is genuinely needed.

Directivity levers (bigger board, arrays) are the wrong tool for this antenna — they narrow
the beam and duplicate the tracked helical.

---

## 7. Lessons from the literature

### From the AEJ 2024 LoRa-MPA review (Yahya et al.)
- **868 MHz patches are low-gain in practice:** the survey's 868 MHz designs cluster at
  **~1.5–5 dBi**, nearly all on FR-4 — consistent with the ceiling seen here.
- **Single-feed CP is hard at this frequency:** the review cites a truncated-corner multilayer
  CP patch (with a metamaterial gain boost, ~2 dBi) and a design stuck at **AR ≈ 7.2 dB**.
  Narrow AR is the characteristic single-feed failure mode.
- **Substrate guidance:** for gain, choose **low permittivity and low loss tangent**; high εr
  shrinks size but increases loss.
- **Enhancement levers it catalogues** (relevant while staying on FR-4):
  - **EBG** (electromagnetic band-gap) ground structures — suppress surface waves, raising
    gain/efficiency on lossy or thick substrates.
  - **Metamaterial** (split-ring) and **dielectric/FSS superstrate** — gain.
  - **DRA** (dielectric resonator) — low loss, wide impedance bandwidth.
  - **Corrugation** (bull's-eye / leaky-wave) — high gain from a planar aperture.
- Tools used in the field: CST, HFSS, FEKO, ADS (this repo uses openEMS — comparable FDTD).
  Target **SWR < 1.5** for the match.

### The adjacent goldmine: UHF RFID reader antennas (865–868 MHz)
EU UHF RFID sits at **865–868 MHz** — essentially this frequency — and RFID readers
overwhelmingly use **CP patch** antennas (dual-feed/hybrid or truncated single-feed,
~6–9 dBic, often air/foam or thick substrate). These are the most directly transferable
real-world designs. GNSS (1.2–1.6 GHz) CP-patch design *methods* also transfer directly.

### Pitfalls the literature keeps repeating
- **Narrow AR is the central single-feed weakness** (AR BW ≈ 1/(√2·Q0)). On a thin, high-Q
  board it is the binding constraint; the only structural fix is lower Q (§6).
- **Manufacturing sensitivity:** a high-Q truncation is small and CP is very sensitive to
  fabrication error. Low-Q designs get a bigger, more forgiving truncation.
- **Polarisation sense:** the wrong diagonal gives LHCP and ~20 dB loss. Lock the sense in
  simulation and re-verify on the physical part.
- **Don't over-reach on bandwidth:** the telemetry channel is ~250 kHz wide. A CP null centred
  on the channel is what matters, not a broad AR band for its own sake.
- **Meshing and convergence:** mesh the thin truncated corners finely and check AR convergence
  — an under-resolved model reports *optimistic* AR (§3).

---

## 8. EU 868 regulatory notes (CEPT/ERC 70-03; ETSI EN 300 220 / EN 302 208)
- **Telemetry channel:** **869.4–869.65 MHz** is the EU high-power SRD sub-band —
  **500 mW e.r.p. (27 dBm)** with **≤10 % duty cycle OR LBT+AFA**. 869.525 MHz sits squarely
  here. (The old "g3" letter label is from earlier ERC 70-03 editions; recent editions
  renumber, but the limits stand.)
- **RFID reuse band (design source, *not* this link):** **865–868 MHz**, ETSI **EN 302 208**,
  up to **2 W e.r.p.** on 200 kHz channels. ~1.5–4.5 MHz below 869.525 → RFID CP-patch designs
  transfer directly, but their power/channel rules are a *separate* allocation — don't apply
  them to the 869.525 link.
- **Wider 863–870 SRD context:** lower sub-bands (868.0–868.6, 868.7–869.2, …) are 25 mW;
  869.4–869.65 at 500 mW is the *only* high-power slot — which is why telemetry uses it.
- **Practical:** the duty/power caps are **transmitter** obligations; a receive-only ground
  antenna isn't power-limited. Design and measure for clean RHCP and |S11| ≤ −10 dB across at
  least **869.4–869.65 MHz**. Keep any TX EIRP ≤ 27 dBm e.r.p. (antenna gain and cable
  accounted for).

---

## 9. The build

**One flat 2-layer NP-140F PCB.** RHCP from **truncating two diagonal corners** of a
near-square patch; ONE inset microstrip feed to ONE edge-launch SMA. No coupler, no
termination resistor, no air gap, no probe, no standoffs. Order → solder one SMA → done.

| Item | Spec | Note |
|---|---|---|
| **Board** | 2-layer **NP-140F, 1.6 mm, 160×160 mm** (centred patch, 4× M3) | top = patch + feed; bottom = ground. Design εr 4.15 @ 870 MHz. |
| **Patch** | near-square **W = 82.5 mm**, two diagonal corners chamfered **Δ = 8.25 mm** | CP from the truncation; BL+TR diagonal → **RHCP at +z** |
| **Feed** | ONE inset microstrip, −y edge centre, **5.8 mm** inset → edge-launch SMA | 50 Ω; no coupler, no resistor — all accepted power goes to the patch |
| **Ground** | 160 mm → **wide beam** (coverage) | locked for coverage; bigger = narrower beam (§4) |
| **Simulated** | **AR 1.04 dB boresight**, AR ≤ 3 dB over a **152° beam** / **6.5 MHz** band, worst **1.66 dB** over the ±45° cone, **S11 −12.6 dB**, directivity **6.6 dBi**, η_rad **29 %**, realised **+1.0 dBic**, RHCP | AR null on f_target; `fab/results.json` |
| **Cost** | **~€25–45 for 5** (1 PCB + 1 SMA) | + coax and radome per station |

Build details and sourcing: [bom.csv](bom.csv). Gerbers and the as-built KiCad project are in
`fab/`.

### Acceptance gates
- **Per-board cold-AR test (required, not optional).** The CP null is a **6.5 MHz** band while
  ±0.1 εr alone shifts it ~±10 MHz, and temperature adds a second drift of the same order — the
  band is narrower than the spread, so CP cannot be assumed from the simulation. Measure each
  board's boresight AR at 869.525 MHz and bin or tune it. Do this at the **cold operating
  extreme**, not just at room temperature: the cold side breaks first. A board that lands
  near-linear falls back to ~−3 dB polarisation loss and the link still closes in this backup
  role, but it must be a known board, not a surprise.
- **εr sensitivity (measured — `tests/tool_eps_sweep.py`).** The null moves ~**−10 MHz per
  +0.1 εr**, so only εr ≈ 4.15 keeps AR ≤ 3 dB inside the channel; at ±0.1 εr the boresight AR
  at f_target degrades to **8–13 dB** (effectively linear). A ±0.1 mm thickness tolerance is
  harmless by comparison. This is what makes the per-board gate mandatory rather than advisory.
- **Thermal CP window (`tests/tool_thermal_drift.py`).** TCDk(εr) + CTE walk the null by
  ~**+0.11 MHz/°C** (≈ +8 MHz across −15…+55 °C) — a second drift source stacked on the lot
  spread, which a one-time room-temperature tune cannot cancel. CP holds from roughly 0 to
  55 °C but **fails at −15 °C** (AR ~3.5 dB): the cold side breaks first. ⚠️ These coefficients
  are **placeholder FR-4 values** — the real window needs NP-140F's datasheet TCDk and CTE.
- **Laminate confirmation.** Get NP-140F at 160×160 confirmed in writing (§5), together with
  the datasheet TCDk and CTE needed to pin the thermal CP window.
- **Sense verification.** Confirm RHCP from the far field (E_R vs E_L) and against the rocket's
  RHCP QFH and the ground helical's winding (§1).
- **Un-simulated hardware.** The radome acts as a superstrate and detunes the CP null downward,
  and the real SMA launch transition (the microstrip neck, 3.2 → 0.61 mm, adds ~3 nH) sits
  outside the idealised port model. Check both before committing a station build.

### Analysis tools
Re-runnable harnesses in `tests/` — all read the locked dims from `config.py`, and their JSON
outputs are gitignored as regenerable:

| Script | Purpose |
|---|---|
| `tool_eps_sweep.py` | εr / thickness robustness of the CP null |
| `tool_trunc_bw_sweep.py` | (W × truncation) drift-margin sweep |
| `tool_thermal_drift.py` | TCDk + CTE temperature CP window |
| `board_sweep.py` | AR ≤ 3 dB beamwidth vs ground-plane size |
| `stage0_dipole_calibration.py` | far-field NF2FF calibration gate (lossless dipole) |
| `stage1_single_feed.py`, `stage3_optimizer.py` | resonance scan; optimiser smoke test |
| `tool_build_inspect.py`, `tool_show_geometry.py`, `tool_link_budget.py` | mesh/geometry inspection, viewer, link budget |

---

## 10. References / further reading
*All citation-checked (DOIs/URLs verified to resolve and match). ★ = closest precedents for
single-feed CP patch design at this frequency.*

**Design method**
- **Sharma, P. C. & Gupta, K. C.** "Analysis and Optimized Design of Single Feed Circularly
  Polarized Microstrip Antennas." *IEEE TAP* 31(6), 1983, 949–955.
  doi:10.1109/TAP.1983.1143162. — *The* single-feed CP recipe: dS/S ≈ 1/(2Q),
  diagonal → RHCP. **Primary method reference.**
- **Lee, Sambell, et al.** "A Design Procedure for a Circularly Polarized, Nearly Square Patch
  Antenna." *Microwave Journal* (art. 935). — perturbation-segment procedure (2.45 GHz worked
  example).
- "Single-feed Corner-Truncated Microstrip CP Antenna CAD Design." *IEEE* (doc 9772892). —
  CAD procedure + closed-form Q (frequency-agnostic).
- Balanis, *Antenna Theory*, Ch. 14 — cavity model, CP, ground-plane effects, AR.

**★ CP patches at UHF RFID frequencies (closest precedents)**
- **★ Cheng, K., Lim, E. H. & Phua, Y. N.** "Circularly Polarized Suspended Patch Antenna Fed
  by Modified L-Probe for UHF RFID Reader." *Radioengineering* 26(4), 2017, 1033–1040 (open:
  radioeng.cz). — Suspended air patch + modified L-probe (an extra bend gives an S11 knob that
  does not spoil AR). 5.5 % AR BW, **9.7 dBic** single / **14.7 dBic** 2×2, ~890–940 MHz →
  scale ×~1.05 for 869.525.
- **Nestoros, Christou & Polycarpou.** "Design of Wideband CP Patch Antennas for RFID …
  FCC/ETSI UHF Bands." *PIER C* 78, 2017, 115–127. doi:10.2528/PIERC17071801 (open). — Air
  single and stacked truncated-corner, 865–928 MHz, 8.3 / 9.3 dBic.
- "A Universal UHF RFID Reader Antenna." *IEEE TMTT* 57(5), 2009 (doc 4806172). — 2
  corner-truncated patches + suspended feed + 4 sequential probes: 8.3 dBic, AR < 3 dB and
  ~75° AR beamwidth over 818–964 MHz (16.4 %).
- **Li, J., et al.** "A Wideband Single-Fed CP Patch Antenna With Enhanced AR Bandwidth for UHF
  RFID." *IEEE Access* 6, 2018, 55883–55892. doi:10.1109/ACCESS.2018.2872692 (open). —
  techniques to widen single-feed AR.

**On-band (868 MHz) benchmarks & context**
- "Low Cost Circularly Polarized Antenna for IoT Space Applications." *MDPI Electronics*
  9(10):1564, 2020. doi:10.3390/electronics9101564. — 868 MHz RHCP on cheap FR-4, ~3 dBic,
  ~50 MHz BW (realistic cheap-build benchmark).
- "Design of Circular Polarized Dual Band Patch Antenna" (MSc thesis, DIVA diva2:528320). —
  868 MHz CP patch, worked design, ~24 MHz BW.
- **Nguyen, Ferrero & Trinh.** "Compact UHF CP Multi-Band Quadrifilar Antenna for CubeSat."
  *MDPI Sensors* 23(12):5361, 2023. doi:10.3390/s23125361. — RHCP **QFH** at 868/915/923,
  77×77×10 mm — the rocket-side analogue.
- **Yahya, M. S. et al.** "LoRa Microstrip Patch Antenna: A comprehensive review." *Alexandria
  Engineering Journal* 103 (2024) 197–221. doi:10.1016/j.aej.2024.06.045. — field survey:
  868 MHz patches ~1.5–5 dBi; EBG / metamaterial / DRA / corrugation enhancement levers.

**Regulatory**
- CEPT/ERC **Recommendation 70-03** (current edition) — EU SRD band plan.
- ETSI **EN 300 220** (non-specific SRD) and **EN 302 208** (UHF RFID).

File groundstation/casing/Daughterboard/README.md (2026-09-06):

# Daughterboard Casing



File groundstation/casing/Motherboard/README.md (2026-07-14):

# Motherboard Casing

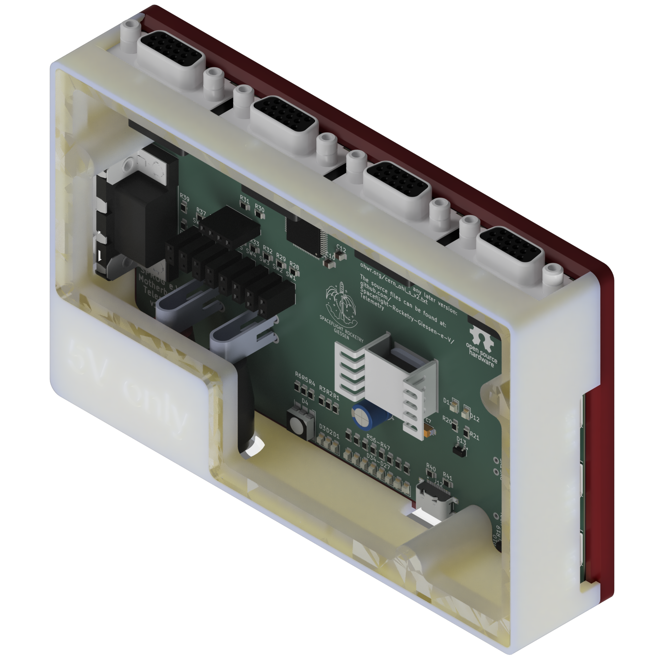
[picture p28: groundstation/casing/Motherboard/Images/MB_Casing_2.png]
|  |  |
|---|---|

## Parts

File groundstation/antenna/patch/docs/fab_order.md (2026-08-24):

# Fab order — JLCPCB

Ordering checklist for the 869.525 MHz RHCP patch board. Parts list is in
[bom.csv](bom.csv); the design rationale behind these numbers is in
[research.md](research.md) (§5 cost/laminate, §9 build + acceptance gates).

> ## ⛔ Two things to settle BEFORE you order
>
> 1. **Re-plot the Gerbers.** The Gerbers tracked in `fab/gerbers/` are **stale** — see
>    [Gerber status](#gerber-status) below. Re-export them from the current board first.
> 2. **Confirm the laminate εr in writing.** JLCPCB's standard FR-4 is **not** NP-140F, and the
>    wrong εr detunes the antenna by ~25 MHz — see [Laminate](#laminate--the-one-that-matters).

---

## JLCPCB order form

| Field | Setting | Note |
|---|---|---|
| Base Material | FR-4 | |
| Layers | 2 | |
| Dimension | 160 × 160 mm | square, centred patch |
| PCB Qty | 5 | |
| Product Type | Industrial/Consumer electronics | |
| Different Design | 1 | |
| Delivery Format | Single PCB | no panelisation |
| PCB Thickness | **1.6 mm** | locked; 3.2 mm is not offered here (JLC caps at 2.0 mm) |
| PCB Color | any (green) | cosmetic — the top copper is mask-free anyway |
| Silkscreen | White | |
| Surface Finish | **Lead-free HASL** (default) or **ENIG** | see [Surface finish](#surface-finish) |
| Outer Copper Weight | **1 oz** (35 µm) | matches the exported stackup; 2 oz optional (+0.1–0.2 dB) |
| Board Outline Tolerance | Regular ±0.2 mm | design rule is 0.2 mm |
| Via Covering | Tented | only 4 RF vias; not critical |
| Min via / hole | Default | smallest hole is 0.4 mm — inside standard capability |
| Impedance Control | **No** | it forces JLC's own stackup + εr, which fights the NP-140F requirement |
| Castellated Holes | **No** | the end-launch SMA solders to top+bottom edge pads; no edge plating needed |
| Gold Fingers | No | |
| Remove Order Number | **Yes** (or specify bottom) | the top is exposed copper — keep JLC's mark off the patch |
| Electrical Test | Fully test (default) | |
| Confirm Production File | not required, but **expect a query** | JLC will likely flag the fully-open top mask — it is intentional |

---

## Laminate — the one that matters

The antenna's CP only lands on-channel at **εr ≈ 4.15** (Nan Ya **NP-140F**, or an equivalent
datasheet-specified FR-4-class laminate). JLCPCB's economy tier ships whatever Tg130–140 stock
they have loaded — typically **KingBoard/Shengyi KB-6164-class, εr ≈ 4.6** — which lands the
patch **~25 MHz low**. You cannot pick NP-140F from the standard dropdown.

Before ordering, either:
- open a support ticket / use the order **Remarks** to get the actual base material **and its Dk
  confirmed in writing**, or
- accept the shift and plan the re-tune (re-run the optimiser at the confirmed εr, re-export).

This is still an open pre-fab gate in [research.md §9](research.md).

## Surface finish

The entire **top copper is intentionally soldermask-free** (it matches the bare-copper
simulation — mask would pull resonance down ~5–10 MHz), so the finish coats a large exposed area.

- **Lead-free HASL (default):** free, RF-negligible at 869 MHz, solders fine for one SMA. The only
  downside is a slightly uneven coating over the large exposed patch, and a slightly less flat
  SMA tab.
- **ENIG (optional, ~$10–15/5):** dead-flat and uniform over the exposed copper and the 0.61 mm
  SMA launch tab. Take it only if you want the connector land perfectly coplanar. Note ENIG's
  nickel is marginally *more* lossy at RF than HASL — negligible here, but "ENIG = better RF" is
  not the reason to pick it.

Either is acceptable; the radome protects the exposed copper.

## Board-specific notes

- **Mounting holes are routed, not drilled.** The four M3 corner holes (8 mm inset) are cut as
  circles in `Edge.Cuts`, so they are absent from the drill file — JLC routs them. Fine, but the
  edges are slightly rougher than a drilled hole. Switching to drilled M3 is a board edit, not an
  order option.
- **The only drilled holes are four 0.4 mm plated vias** at the feed — the SMA-launch ground
  stitching, not mounting holes.
- **Top soldermask fully open** over patch + feed + SMA lands: intentional, already in the Gerbers
  (`F.Mask` openings). Don't let anyone "fix" it.

## Paste into JLCPCB "Remarks"

> 2-layer, 1.6 mm. Top soldermask is intentionally opened over all top copper (bare copper is by
> design — do not add mask). Requesting a laminate with Dk ≈ 4.15 (Nan Ya NP-140F or equivalent) —
> please confirm the actual base material and its Dk before production. Do not print the order
> number on the top (patch) side — bottom silk only.

---

## Gerber status

**The Gerbers in `fab/gerbers/` are stale — re-plot before ordering.**

- They were plotted **2026-06-16** with **KiCad 9.0.7**.
- `fab/patch_antenna.kicad_pcb` was since re-saved in **KiCad 10.0** (last change 2026-08-01,
  `generator_version "10.0"`), so the tracked Gerbers no longer correspond to the current board.
- The geometry difference is confined to a **front-silkscreen** graphic — copper, soldermask,
  board outline, vias and mounting holes are unchanged, so the *electrical and mechanical* board
  is identical. But the export is stale and unverified; don't ship it as-is.

### Version note — you need KiCad 10 to re-plot
The board is a **KiCad 10** file. `kicad-cli` 9.0.x **cannot load it** ("Failed to load board").
Re-plot on a machine with **KiCad 10** (or newer). This is also why the Gerbers drifted: the board
was edited in KiCad 10 on another machine and never re-plotted.

### To refresh (one command)
From the repo root, on a machine with a matching KiCad:

```
pwsh groundstation/antenna/patch/fab/export_gerbers.ps1
```

It locates `kicad-cli`, re-plots `gerbers/` from the board, and writes
`fab/patch_antenna_gerbers.zip` — **upload that zip to JLCPCB.** Then commit the refreshed
`fab/gerbers/` so the folder stays self-consistent. (Manual fallback: KiCad ▸ File ▸ Fabrication
Outputs ▸ Gerbers, then Generate Drill Files.)

### Guard — Gerbers can't silently go stale again
A `pre-commit` hook (`fab/hooks/pre-commit`) **blocks any commit that changes the board without
also staging refreshed Gerbers**. Install it once per machine from the repo root:

```
cp groundstation/antenna/patch/fab/hooks/pre-commit .git/hooks/pre-commit && chmod +x .git/hooks/pre-commit
```

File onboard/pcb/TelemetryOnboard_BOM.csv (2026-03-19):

Reference | Qty | Value | Footprint | DNP | Purchase-URL
C1,C3 | 2 | 4u7 | Capacitor_SMD:C_0805_2012Metric_Pad1.18x1.45mm_HandSolder |  | https://www.digikey.de/de/products/detail/samsung-electro-mechanics/CL21A475KPFNNNE/3886917
C2,C4 | 2 | 0u1 | Capacitor_SMD:C_0805_2012Metric_Pad1.18x1.45mm_HandSolder |  | https://www.digikey.de/de/products/detail/samsung-electro-mechanics/CL21B104KBCNNNC/3886661
C5,C6,C7,C8,C10,C12,C13 | 7 | 1u | Capacitor_SMD:C_0805_2012Metric_Pad1.18x1.45mm_HandSolder |  | https://www.digikey.de/de/products/detail/samsung-electro-mechanics/CL21B105KBFNNNE/3886687
C9,C11 | 2 | 1n | Capacitor_SMD:C_0805_2012Metric_Pad1.18x1.45mm_HandSolder |  | https://www.digikey.de/de/products/detail/samsung-electro-mechanics/CL21B102KCANNNC/3886827
D1,D2,D3,D7,D15,D16,D17,D18,D19 | 9 | orange | LED_SMD:LED_0805_2012Metric_Pad1.15x1.40mm_HandSolder |  | https://www.digikey.de/de/products/detail/liteon/LTST-C170KFKT/386775
D4 | 1 | Cree RGB LED | Footprints:Cree RGB LED |  | https://www.digikey.de/de/products/detail/cree-led/CLP6C-FKB-CKNPRGJBB7A363/6138636
D5,D8 | 2 | SP0503BAHTG | Package_TO_SOT_SMD:SOT-143 |  | https://www.digikey.de/de/products/detail/littelfuse-inc/SP0503BAHTG/1154322
D6,D11,D12,D25,D27 | 5 | green | LED_SMD:LED_0805_2012Metric_Pad1.15x1.40mm_HandSolder |  | https://www.digikey.de/de/products/detail/liteon/LTST-C171KGKT/386799
D9,D20,D21,D22,D23,D28,D29 | 7 | red | LED_SMD:LED_0805_2012Metric_Pad1.15x1.40mm_HandSolder |  | https://www.digikey.de/de/products/detail/liteon/LTST-C171KRKT/386801
D10 | 1 | BAT43 | Diode_SMD:D_SOD-123 |  | https://www.digikey.de/de/products/detail/mcc-micro-commercial-components/BAT43W-TP/717224
D13 | 1 | WE-TVS_SOT23-3L_824021 | Package_TO_SOT_SMD:SOT-23-3 |  | https://www.digikey.de/de/products/detail/w%C3%BCrth-elektronik/824021/3900544
D14 | 1 | MMSD4148T1G | Diode_SMD:D_SOD-123 |  | https://www.digikey.de/de/products/detail/onsemi/MMSD4148T1G/919705
D24,D26 | 2 | yellow | LED_SMD:LED_0805_2012Metric_Pad1.15x1.40mm_HandSolder |  | https://www.digikey.de/de/products/detail/liteon/LTST-C170KSKT/386781
J1,J2 | 2 | USB-C | Footprints:GCT_USB4216-03-A_REVA |  | https://www.digikey.de/de/products/detail/gct/USB4216-03-A/26598207
J3,J4 | 2 | RFPC-SMA28-F | Footprints:RFPC-SMA28-F |  | https://www.digikey.de/de/products/detail/gct/RFPC-SMA28-F/22162141?s=N4IgTCBcDaIE4DMAOBjABAZwLYEMwA4EQBdAXyA
J5 | 1 | Molex_MicroFit_2pin | Footprints:Molex_MicroFit_2pin |  | https://www.digikey.de/de/products/detail/molex/0436500203/268999
JL1,JL2,JL3,JL4 | 4 | Stackable Socket 1x8 | Footprints:JL1,Footprints:JL2,Footprints:JL3,Footprints:JL4 |  | https://www.digikey.de/de/products/detail/samtec-inc/ESQ-108-13-T-S/6692088,~
JR1,JR2,JR3,JR4 | 4 | Stackable Socket 1x8 | Footprints:JR1,Footprints:JR2,Footprints:JR3,Footprints:JR4 |  | https://www.digikey.de/de/products/detail/samtec-inc/ESQ-108-13-T-S/6692088,~
LS1 | 1 | CMT-0525-75-SMT-TR | Footprints:Buzzer XDCR_CMT-0525-75-SMT-TR |  | https://www.digikey.de/de/products/detail/same-sky-formerly-cui-devices/CMT-0525-75-SMT-TR/10326240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
M1,M2,M3,M4 | 4 | M4 Mounting Hole | Footprints:M4 Mounting Hole |  | ~
Q1 | 1 | MMBT4401-TP | Package_TO_SOT_SMD:SOT-23 |  | https://www.digikey.de/de/products/detail/mcc-micro-commercial-components/MMBT4401-TP/717281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
R1,R2,R3,R4,R5,R6,R11,R12,R17,R20,R21,R36,R37,R38,R39,R40,R45,R46,R47,R48 | 20 | 560R | Resistor_SMD:R_0805_2012Metric_Pad1.20x1.40mm_HandSolder |  | https://www.digikey.de/de/products/detail/stackpole-electronics-inc/RMCF0805JT560R/1757876
R7,R8,R13,R14 | 4 | 5k1 | Resistor_SMD:R_0805_2012Metric_Pad1.20x1.40mm_HandSolder |  | https://www.digikey.de/de/products/detail/stackpole-electronics-inc/RNCF0805DTE5K10/6241868
R9,R15 | 2 | 47k | Resistor_SMD:R_0805_2012Metric_Pad1.20x1.40mm_HandSolder |  | https://www.digikey.de/de/products/detail/stackpole-electronics-inc/RMCF0805JT47K0/1757842
R10,R16 | 2 | 22k | Resistor_SMD:R_0805_2012Metric_Pad1.20x1.40mm_HandSolder |  | https://www.digikey.de/de/products/detail/stackpole-electronics-inc/RMCF0805JT22K0/1757908
R18,R19 | 2 | 470R | Resistor_SMD:R_0805_2012Metric_Pad1.20x1.40mm_HandSolder |  | https://www.digikey.de/de/products/detail/stackpole-electronics-inc/RMCF0805JT470R/1757849
R22 | 1 | 180R | Resistor_SMD:R_0805_2012Metric_Pad1.20x1.40mm_HandSolder |  | https://www.digikey.de/de/products/detail/stackpole-electronics-inc/RMCF0805JT180R/1757903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
R23,R24,R25,R26,R27,R28,R29,R30,R31,R33,R35 | 11 | 5k6 | Resistor_SMD:R_0805_2012Metric_Pad1.20x1.40mm_HandSolder |  | https://www.digikey.de/de/products/detail/stackpole-electronics-inc/RMCF0805JT5K60/1757920
R32,R34 | 2 | 2k7 | Resistor_SMD:R_0805_2012Metric_Pad1.20x1.40mm_HandSolder |  | https://www.digikey.de/de/products/detail/stackpole-electronics-inc/RMCF0805JT2K70/1757901
R41,R42,R43,R44,R49,R50 | 6 | 1k | Resistor_SMD:R_0805_2012Metric_Pad1.20x1.40mm_HandSolder |  | https://www.digikey.de/de/products/detail/stackpole-electronics-inc/RMCF0805JT1K00/1757881
TP1,TP2,TP3,TP4,TP5,TP6,TP7,TP8,TP9,TP10,TP11,TP12,TP13,TP14,TP15,TP16,TP17 | 17 | TestPoint | Footprints:Test Point |  | ~
U1,U2 | 2 | CP2102N | Footprints:QFN20_CP2102N_SIL |  | https://www.digikey.de/de/products/detail/silicon-labs/CP2102N-A02-GQFN20/9863475
U3 | 1 | AVR128DB64x-xPT | Package_QFP:TQFP-64_10x10mm_P0.5mm |  | https://www.digikey.de/de/products/detail/microchip-technology/AVR128DB64T-I-PT/12807279
U4 | 1 | RC1780HP-RC232 | Footprints:Radiocrafts RC1780HP-RC232 |  | https://www.digikey.de/de/products/detail/radiocrafts-as/RC1780HP-RC232/7100620
U5 | 1 | RC1701HP-RC232 | Footprints:Radiocrafts RC1780HP-RC232 |  | https://www.digikey.de/de/products/detail/radiocrafts-as/RC1701HP-RC232/7100557
U6 | 1 | W25Q80DVSSIG | Package_SO:SOIC-8_5.3x5.3mm_P1.27mm |  | https://www.digikey.de/de/products/detail/winbond-electronics/W25Q80DVSSIG/4836572
ZP1,ZP2 | 2 | ~ | Resistor_SMD:R_0805_2012Metric_Pad1.20x1.40mm_HandSolder |  | ~
ZS1,ZS2 | 2 | ~ | Resistor_SMD:R_0805_2012Metric_Pad1.20x1.40mm_HandSolder |  | ~

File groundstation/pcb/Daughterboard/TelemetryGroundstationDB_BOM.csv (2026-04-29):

Reference | Qty | Value | Footprint | DNP | Purchase-URL
C1 | 1 | 1n | Capacitor_SMD:C_0805_2012Metric_Pad1.18x1.45mm_HandSolder |  | https://www.digikey.de/de/products/detail/samsung-electro-mechanics/CL21B102KCANNNC/3886827
C2 | 1 | 1u | Capacitor_SMD:C_0805_2012Metric_Pad1.18x1.45mm_HandSolder |  | https://www.digikey.de/de/products/detail/samsung-electro-mechanics/CL21B102KCANNNC/3886827
D1,D3,D4 | 3 | green | LED_SMD:LED_0805_2012Metric_Pad1.15x1.40mm_HandSolder |  | https://www.digikey.de/de/products/detail/liteon/LTST-C171KGKT/386799
D2 | 1 | yellow | LED_SMD:LED_0805_2012Metric_Pad1.15x1.40mm_HandSolder |  | https://www.digikey.de/de/products/detail/liteon/LTST-C170KSKT/386781
D5 | 1 | WE-TVS_SOT23-3L_824021 | Package_TO_SOT_SMD:SOT-23-3 |  | https://www.digikey.de/de/products/detail/w%C3%BCrth-elektronik/824021/3900544
J1 | 1 | RFPC-SMA27-F | Footprints:GRADCONN_RFPC-SMA27-F |  | https://www.digikey.de/de/products/detail/gct/RFPC-SMA27-F/22162144
J2 | 1 | ICD15S13E4GV00LF | Footprints:AMPHENOL_ICD15S13E4GV00LF[1] |  | https://www.digikey.de/de/products/detail/amphenol-cs-fci/ICD15S13E4GV00LF/1536418
M1,M2,M3,M4 | 4 | M4 Mounting Hole | Footprints:M4 Mounting Hole |  | ~
R1 | 1 | 2k7 | Resistor_SMD:R_0805_2012Metric_Pad1.20x1.40mm_HandSolder |  | https://www.digikey.de/de/products/detail/stackpole-electronics-inc/RMCF0805JT2K70/1757901
R2,R3,R7,R8 | 4 | 560R | Resistor_SMD:R_0805_2012Metric_Pad1.20x1.40mm_HandSolder |  | https://www.digikey.de/de/products/detail/stackpole-electronics-inc/RMCF0805JT560R/1757876
R4,R5,R6 | 3 | 5k6 | Resistor_SMD:R_0805_2012Metric_Pad1.20x1.40mm_HandSolder |  | https://www.digikey.de/de/products/detail/stackpole-electronics-inc/RMCF0805JT5K60/1757920
TP1,TP2,TP3,TP4,TP5,TP6 | 6 | TestPoint | Footprints:Test Point |  | ~
U1 | 1 | RC1780HP-RC232 | Footprints:Radiocrafts RC1780HP-RC232 |  | https://www.digikey.de/de/products/detail/radiocrafts-as/RC1780HP-RC232/7100620
ZP1 | 1 | ~ | Resistor_SMD:R_0805_2012Metric_Pad1.20x1.40mm_HandSolder |  | ~
ZS1 | 1 | ~ | Resistor_SMD:R_0805_2012Metric_Pad1.20x1.40mm_HandSolder |  | ~

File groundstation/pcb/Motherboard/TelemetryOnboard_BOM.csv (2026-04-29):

Reference | Qty | Value | Footprint | DNP | Purchase-URL
C1,C3,C6 | 3 | 4.7u | Capacitor_SMD:C_0805_2012Metric_Pad1.18x1.45mm_HandSolder |  | https://www.digikey.de/de/products/detail/samsung-electro-mechanics/CL21A475KPFNNNE/3886917
C2,C4,C5 | 3 | 0.1u | Capacitor_SMD:C_0805_2012Metric_Pad1.18x1.45mm_HandSolder |  | https://www.digikey.de/de/products/detail/samsung-electro-mechanics/CL21B104KBCNNNC/3886661
C7 | 1 | 10u Tantal | Footprints:CAPMP3216X180N |  | https://www.digikey.de/en/products/detail/kyocera-avx/TAJA106M010RNJ/564869
C9,C10,C11,C12 | 4 | 1u | Capacitor_SMD:C_0805_2012Metric_Pad1.18x1.45mm_HandSolder |  | https://www.digikey.de/de/products/detail/samsung-electro-mechanics/CL21B105KBFNNNE/3886687
C13 | 1 | 100u Elko | Capacitor_THT:CP_Radial_D6.3mm_P2.50mm |  | https://www.digikey.de/en/products/detail/elna-america/RSRC2101M1ED07119T/7042186
D1,D2,D3,D7,D16,D27,D28,D29,D30,D31,D32,D33,D34 | 13 | orange | LED_SMD:LED_0805_2012Metric_Pad1.15x1.40mm_HandSolder |  | https://www.digikey.de/de/products/detail/liteon/LTST-C170KFKT/386775
D4 | 1 | Cree RGB LED | Footprints:Cree RGB LED |  | https://www.digikey.de/de/products/detail/cree-led/CLP6C-FKB-CK1P1G1BB7R3R3/2341952
D5,D8,D14 | 3 | SP0503BAHT | Package_TO_SOT_SMD:SOT-143 |  | https://www.digikey.de/en/products/detail/littelfuse-inc/SP0503BAHTG/1154308
D6,D11,D12,D15 | 4 | green | LED_SMD:LED_0805_2012Metric_Pad1.15x1.40mm_HandSolder |  | https://www.digikey.de/de/products/detail/liteon/LTST-C171KGKT/386799
D9 | 1 | red | LED_SMD:LED_0805_2012Metric_Pad1.15x1.40mm_HandSolder |  | https://www.digikey.de/de/products/detail/liteon/LTST-C171KRKT/386801
D10 | 1 | BAT43 | Diode_SMD:D_SOD-123 |  | https://www.digikey.de/en/products/detail/mcc-micro-commercial-components/BAT43W-TP/717224
D13 | 1 | WE-TVS_SOT23-3L_824021 | Package_TO_SOT_SMD:SOT-23-3 |  | https://www.digikey.de/en/products/detail/w%C3%BCrth-elektronik/824021/3900544
J1,J2,J4,J12 | 4 | USB-C | Footprints:GCT_USB4216-03-A_REVA |  | https://www.digikey.de/en/products/detail/gct/USB4216-03-A/26598207
J3,J5,J6,J7 | 4 | ICD15S13E4GV00LF | Footprints:AMPHENOL_ICD15S13E4GV00LF[1] |  | https://www.digikey.de/en/products/detail/amphenol-cs-fci/ICD15S13E4GV00LF/1536418
J8 | 1 | LD09S33E4GV00LF | Footprints:AMPHENOL_LD09S33E4GV00LF |  | https://www.digikey.de/en/products/detail/amphenol-cs-fci/LD09S33E4GV00LF/4997294
J9 | 1 | Conn_01x04_Socket | Connector_PinSocket_2.54mm:PinSocket_1x04_P2.54mm_Vertical |  | ~
J10,J11 | 2 | Conn_01x01 | Footprints:Banana_CT3151-0,Footprints:Banana_CT3151-2 |  | ~
M1,M2,M3,M4 | 4 | M4 Mounting Hole | Footprints:M4 Mounting Hole |  | ~
R1,R2,R3,R4,R5,R6,R11,R12,R17,R20,R21,R25,R26,R37,R47,R48,R51,R52,R53,R54,R55,R56 | 22 | 560R | Resistor_SMD:R_0805_2012Metric_Pad1.20x1.40mm_HandSolder |  | https://www.digikey.de/de/products/detail/stackpole-electronics-inc/RMCF0805JT560R/1757876
R7,R8,R13,R14,R22,R27,R40,R41 | 8 | 5k1 | Resistor_SMD:R_0805_2012Metric_Pad1.20x1.40mm_HandSolder |  | https://www.digikey.de/en/products/detail/stackpole-electronics-inc/RNCF0805DTE5K10/6241868
R9,R15,R24 | 3 | 47k | Resistor_SMD:R_0805_2012Metric_Pad1.20x1.40mm_HandSolder |  | https://www.digikey.de/en/products/detail/stackpole-electronics-inc/RMCF0805JT47K0/1757842
R10,R16,R23 | 3 | 22k | Resistor_SMD:R_0805_2012Metric_Pad1.20x1.40mm_HandSolder |  | https://www.digikey.de/en/products/detail/stackpole-electronics-inc/RMCF0805JT22K0/1757908
R18,R19 | 2 | 470R | Resistor_SMD:R_0805_2012Metric_Pad1.20x1.40mm_HandSolder |  | https://www.digikey.de/en/products/detail/stackpole-electronics-inc/RMCF0805JT470R/1757849
R28,R29,R30,R31,R32,R33,R34,R35,R36,R38,R39 | 11 | 5k6 | Resistor_SMD:R_0805_2012Metric_Pad1.20x1.40mm_HandSolder |  | https://www.digikey.de/en/products/detail/stackpole-electronics-inc/RMCF0805JT5K60/1757920
SW1,SW2,SW3,SW4,SW5,SW6,SW7 | 7 | SW_Push | Connector_PinSocket_2.54mm:PinSocket_1x02_P2.54mm_Vertical |  | ~
SW8 | 1 | SW_DIP_x01 | Connector_PinSocket_2.54mm:PinSocket_1x02_P2.54mm_Vertical |  | ~
TP1,TP2,TP3,TP6,TP7 | 5 | TestPoint | Footprints:Test Point |  | ~
U1,U2,U3 | 3 | CP2102N | Footprints:QFN20_CP2102N_SIL |  | https://www.digikey.de/en/products/detail/silicon-labs/CP2102N-A02-GQFN20/9863475
U5 | 1 | AVR128DB64x-xPT | Package_QFP:TQFP-64_10x10mm_P0.5mm |  | https://www.digikey.de/de/products/detail/microchip-technology/AVR128DB64T-I-PT/12807279
U6 | 1 | MIC29300-3.3WU-TR | Footprints:MIC29300 |  | https://www.digikey.de/en/products/detail/microchip-technology/MIC29300-3-3WU-TR/1029111

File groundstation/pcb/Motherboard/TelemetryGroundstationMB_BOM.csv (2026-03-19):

Reference | Qty | Value | Footprint | DNP | Purchase-URL
C1,C3,C6 | 3 | 4.7 uF | Capacitor_SMD:C_0805_2012Metric_Pad1.18x1.45mm_HandSolder
C2,C4,C5 | 3 | 0.1 uF | Capacitor_SMD:C_0805_2012Metric_Pad1.18x1.45mm_HandSolder
C7 | 1 | 10uF Tantal | Footprints:CAPMP3216X180N
C9,C10,C11,C12 | 4 | 1 uF | Capacitor_SMD:C_0805_2012Metric_Pad1.18x1.45mm_HandSolder |  | https://www.digikey.de/de/products/detail/samsung-electro-mechanics/CL21B105KAFNNNE/3886724
C13 | 1 | 100uF Elko | Capacitor_THT:CP_Radial_D6.3mm_P2.50mm
D1,D2,D3,D7,D16,D27,D28,D29,D30,D31,D32,D33,D34 | 13 | orange | LED_SMD:LED_0805_2012Metric_Pad1.15x1.40mm_HandSolder |  | https://www.digikey.de/de/products/detail/liteon/LTST-C170KFKT/386775
D4 | 1 | Cree RGB LED | Footprints:Cree RGB LED
D5,D8,D14 | 3 | SP0503BAHT | Package_TO_SOT_SMD:SOT-143
D6,D11,D12,D15 | 4 | green | LED_SMD:LED_0805_2012Metric_Pad1.15x1.40mm_HandSolder
D9 | 1 | red | LED_SMD:LED_0805_2012Metric_Pad1.15x1.40mm_HandSolder
D10 | 1 | BAT43 | Diode_SMD:D_SOD-123
D13 | 1 | WE-TVS_SOT23-3L_824021 | Package_TO_SOT_SMD:SOT-23-3
J1,J2,J4,J12 | 4 | USB-C | Footprints:GCT_USB4216-03-A_REVA
J3,J5,J6,J7 | 4 | ICD15S13E4GV00LF | Footprints:AMPHENOL_ICD15S13E4GV00LF[1]
J8 | 1 | LD09S33E4GV00LF | Footprints:AMPHENOL_LD09S33E4GV00LF
J9 | 1 | Conn_01x04_Socket | Connector_PinSocket_2.54mm:PinSocket_1x04_P2.54mm_Vertical
J10,J11 | 2 | Conn_01x01 | Footprints:Banana_CT3151-0
M1,M2,M3,M4 | 4 | M4 Mounting Hole | Footprints:M4 Mounting Hole
R1,R2,R3,R4,R5,R6,R11,R12,R17,R20,R21,R25,R26,R37,R47,R48,R51,R52,R53,R54,R55,R56 | 22 | 560 Ohm | Resistor_SMD:R_0805_2012Metric_Pad1.20x1.40mm_HandSolder |  | https://www.digikey.de/de/products/detail/yageo/RC0805JR-07270RL/728291
R7,R8,R13,R14,R22,R27,R40,R41 | 8 | 5k1 | Resistor_SMD:R_0805_2012Metric_Pad1.20x1.40mm_HandSolder
R9,R15,R24 | 3 | 47k | Resistor_SMD:R_0805_2012Metric_Pad1.20x1.40mm_HandSolder
R10,R16,R23 | 3 | 22k | Resistor_SMD:R_0805_2012Metric_Pad1.20x1.40mm_HandSolder
R18,R19 | 2 | 470 Ohm | Resistor_SMD:R_0805_2012Metric_Pad1.20x1.40mm_HandSolder
R28,R29,R30,R31,R32,R33,R34,R35,R36,R38,R39 | 11 | 5k6 | Resistor_SMD:R_0805_2012Metric_Pad1.20x1.40mm_HandSolder
SW1,SW2,SW3,SW4,SW5,SW6,SW7 | 7 | SW_Push | Connector_PinSocket_2.54mm:PinSocket_1x02_P2.54mm_Vertical
SW8 | 1 | SW_DIP_x01 | Connector_PinSocket_2.54mm:PinSocket_1x02_P2.54mm_Vertical
TP1,TP2,TP3,TP6,TP7 | 5 | TestPoint | Footprints:Test Point
U1,U2,U3 | 3 | CP2102N | Footprints:QFN20_CP2102N_SIL
U5 | 1 | AVR128DB64x-xPT | Package_QFP:TQFP-64_10x10mm_P0.5mm |  | https://www.digikey.de/de/products/detail/microchip-technology/AVR128DB64T-I-PT/12807279
U6 | 1 | MIC29300-3.3WU-TR | Footprints:MIC29300

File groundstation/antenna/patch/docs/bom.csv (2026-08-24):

line | item | spec | qty | reichelt | reichelt_eur | reichelt_url | digikey | digikey_eur | digikey_url | alt_source | alt_url | notes
1 | Patch + feed board | single 2-layer NP-140F (Tg135, design er 4.15; datasheet 4.0-4.2 @ 1GHz) 1.6mm, 160x160mm: TOP = near-square patch (~83mm) with TWO diagonally-opposite corners chamfered (the CP perturbation) + ONE inset 50ohm microstrip feed to the edge-launch SMA land (+ inset notch), soldermask keep-out over all RF copper; BOTTOM = full ground. WR-SMA end-launch land pattern + 4x M3 mounting holes | 5 | (custom PCB - n/a) | - | - | (custom PCB - JLCPCB) | ~5-9 ea | https://cart.jlcpcb.com/quote | JLCPCB / PCBWay custom Gerber | https://cart.jlcpcb.com/quote | ~25-45 EUR/5 incl ship+VAT. ALL RF geometry etched (reproducible) - no air, no probe, no slot, NO coupler, NO termination resistor. 160mm=256cm2, cheap tier. 160mm chosen for MAX AR<=3 beamwidth (smaller GP = wider beam). NP-140F guaranteed-if-picked = known er -> resonance lands on bench. RHCP comes from the corner truncation (mode-split), fed by a single inset microstrip - single-feed only (no coupler, no termination resistor).
2 | SMA connector (edge/end-launch) | end-launch SMA jack, 50 ohm DC-6GHz, for a 1.6mm board edge: flat centre tab lands on the top 50ohm microstrip neck, flat ground wings wrap to the bottom GP - no through-board via needed. THIS is the microstrip launch (the board carries WE's qualified land pattern). Vertical PCB jack = OK fallback (needs a launch pad + ground vias) | 5-8 | BKL 0409074 vertical PCB jack 50ohm (fallback) | ~3-5 | https://www.reichelt.com/de/en/build-in-sma-socket-pcb-type-180--bkl-0409074-p280458.html | Wuerth 60312202114514 (end-launch, flat tab, 1.6mm) PRIMARY - board land pattern matches this part | ~5.86 ea | https://www.digikey.com/en/products/detail/w%C3%BCrth-elektronik/60312202114514/10106999 | Adafruit 1865 edge-launch 1.6mm (~3-4 ea); Mouser/Farnell 3583890; RS 181-0102 | https://www.adafruit.com/product/1865 | Edge-launch = clean microstrip launch (no via, ideal for the single edge feed); very forgiving at 869MHz. Reichelt stocks no true edge-launch -> order the Wuerth 60312202114514 (the board land pattern is drawn for it), or the Adafruit edge-launch, OR use the BKL vertical jack with a launch pad + ground vias. One per board.
3 | Feed coax | RG-316 (or LMR-200) SMA jumper to the RC1780HP 869 MHz radio, ~1-2 m (PER STATION) | 1-2 | Delock RG-316 SMA jumper | ~8-12 | https://www.reichelt.com/de/en/ | Cinch 415-0029-M1.0 / J10288-ND (RG-316 1m) | ~20 | https://www.digikey.com/en/products/detail/cinch-connectivity-solutions-johnson/415-0029-M1-0/6579660 | bulk RG-316 + crimp plugs (Koax24) | https://www.koax24.de/ | SMA-male to suit the radio. Per deployed station - not necessarily 5.
4 | Enclosure tray (3D-printed) | printed weather-sealed tray from casing/enclosure.py -> casing/enclosure.scad (OpenSCAD). External 170x170x21.6mm + 12mm mount ears on +/-X; 4mm all-perimeter-solid wall, 4mm floor; cavity 162mm; nylon-self-tap standoff bosses; teardrop coax bore; ePTFE breather seat. ASA or ABS filament (UV/weather stable) | 1 | (print in-house) | - | - | (print in-house) | - | - | ASA/ASA-CF filament, ~200mm bed footprint incl brim | - | PER STATION. Replaces the earlier off-the-shelf box. Print all-perimeter solid for watertightness; build-time asserts in enclosure.py enforce the DFM/seal rules. Bed >=220mm axis-aligned.
5 | Radome window (acrylic) | cast acrylic (PMMA) sheet 166.2 x 166.2 x 3.0mm, R10 corners - cut to casing/radome_window.dxf. Drops into the tray's locating lip and rests on the hard ledge (this ledge sets the 10mm patch-to-window air gap) | 1 | local laser/CNC cutter | - | - | - | - | - | any acrylic laser-cutting service (DXF supplied) | - | PER STATION. RF-transparent - NO metal, foil, tint layer or metallised coating over the patch. Acrylic acts as a superstrate and detunes the CP null slightly - see the radome gate in docs/research.md.
6 | Board fasteners | NYLON M3 screws, ~8-10mm, self-tapping straight into the printed standoff bosses (2.5mm pilot). NO brass heat-set inserts and no metal standoffs | 4 | nylon M3 screw assortment | - | - | - | - | - | any nylon/polyamide M3 screw set | - | RF-CRITICAL: nylon only. Any metal at or above the ground plane detunes the patch and spoils the CP - this is why the standoffs are all-plastic.
7 | Gasket cord + sealant | closed-cell foam gasket cord for a 1.5mm wide x 1.0mm deep groove (wall top, inboard); plus RTV/acrylic sealant for the 0.4mm window-to-lip clearance | 1 | foam gasket cord + RTV | - | - | - | - | - | generic sealing foam cord / neutral-cure RTV | - | PER STATION. The seal is carried by the gasket ribs plus the window lip bond.
8 | Breather vent (ePTFE) | adhesive ePTFE/Gore breather patch for a 6mm through-hole with a 14mm exterior recess seat, in the floor (behind the ground plane -> RF-safe) | 1 | adhesive ePTFE vent patch | - | - | - | - | - | Gore/ePTFE adhesive vent patch | - | PER STATION. Defeats condensation in a permanently sealed box across -15..55degC - a dew film on the radome is high-permittivity and wrecks the CP.

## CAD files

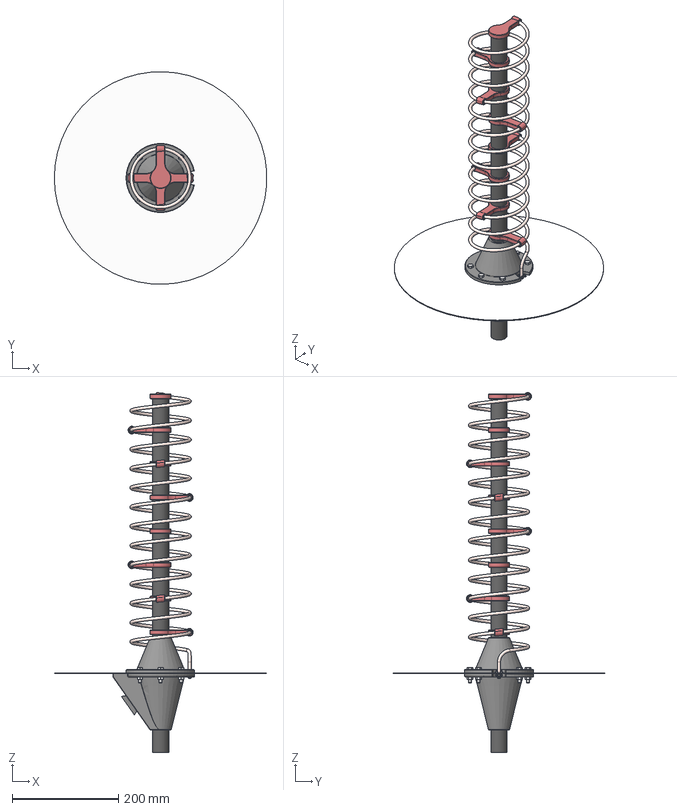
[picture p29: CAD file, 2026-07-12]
groundstation/antenna/helical/Antenna Assembly.step
399.6 x 399.8 x 677.5 mm
CONSMA016-15-G
DIN EN 24018 - M6 x 25 Stahl 4.6 Einfach x 6
BSHCS ANSI B18.3.1M - M2.5x0.45 x 8 Stahlklasse 2 Einfach x 4
DIN 970 - M2.5 Stahl 6 Einfach x 4
ISO 4032 - M6 Stahl 6 Einfach x 6

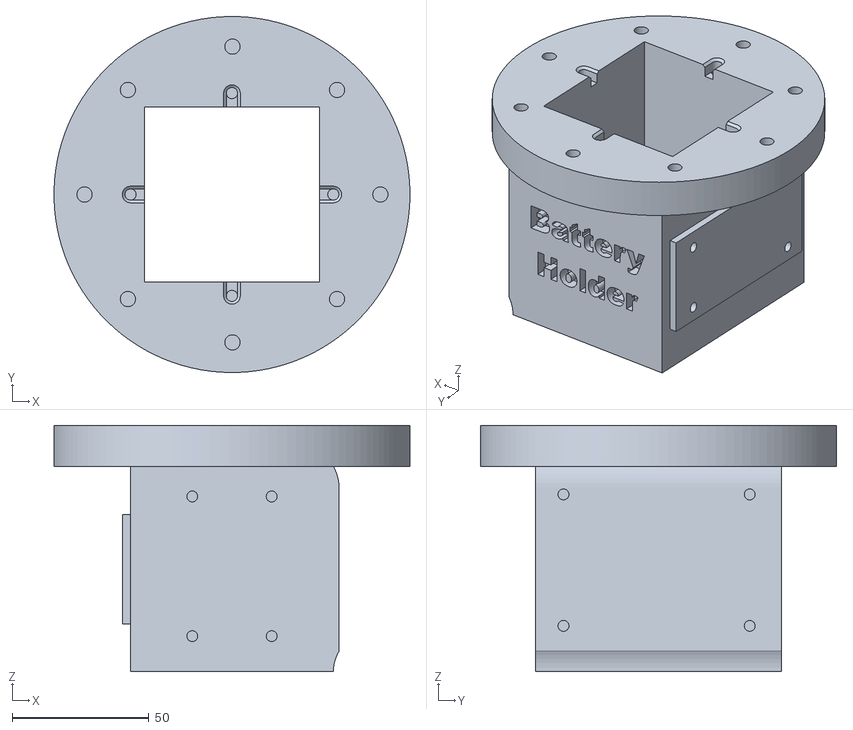
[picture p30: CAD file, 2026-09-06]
groundstation/casing/Daughterboard/Auxiliary Desing Files/main_bat.stl
130.0 x 130.0 x 90.0

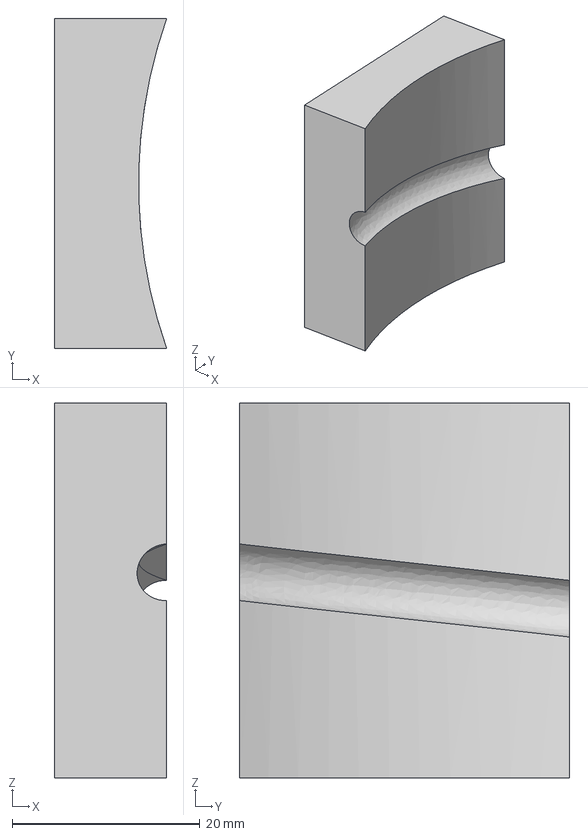
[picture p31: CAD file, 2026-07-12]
groundstation/antenna/helical/Auxiliary Design Files/Winding Clamp.step
12.0 x 35.2 x 40.0 mm

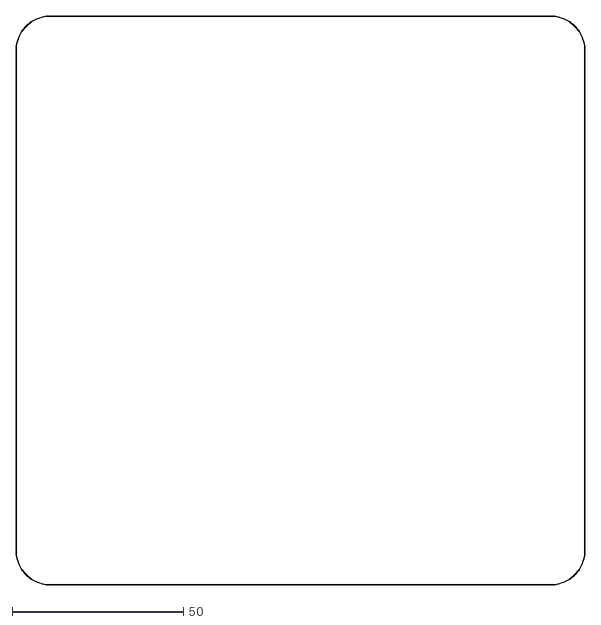
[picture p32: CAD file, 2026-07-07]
groundstation/antenna/patch/casing/radome_window.dxf
166.2 x 166.2

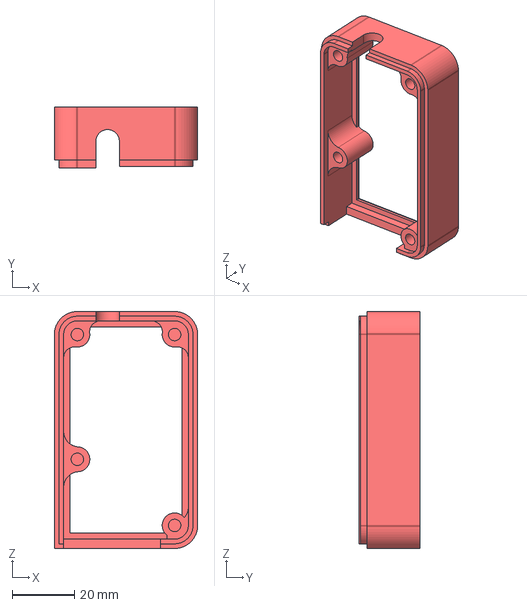
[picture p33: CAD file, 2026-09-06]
groundstation/casing/Daughterboard/Auxiliary Desing Files/Daughterboard Casing Top Shell.step
46.0 x 19.5 x 76.0 mm

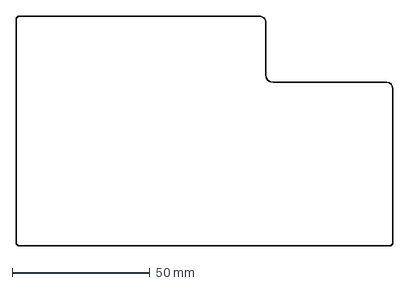
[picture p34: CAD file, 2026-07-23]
groundstation/casing/Motherboard/Auxiliary Design Files/Acrylic.dxf
136.6 x 83.4 mm

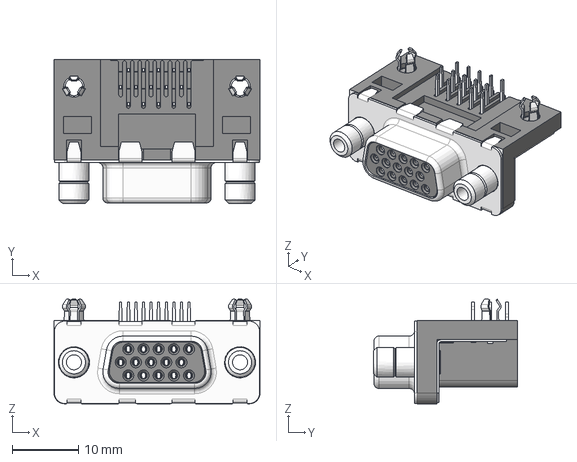
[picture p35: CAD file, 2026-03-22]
groundstation/pcb/Daughterboard/3D Models/ICD15S13E4GV00LF.step
31.0 x 21.6 x 15.8 mm

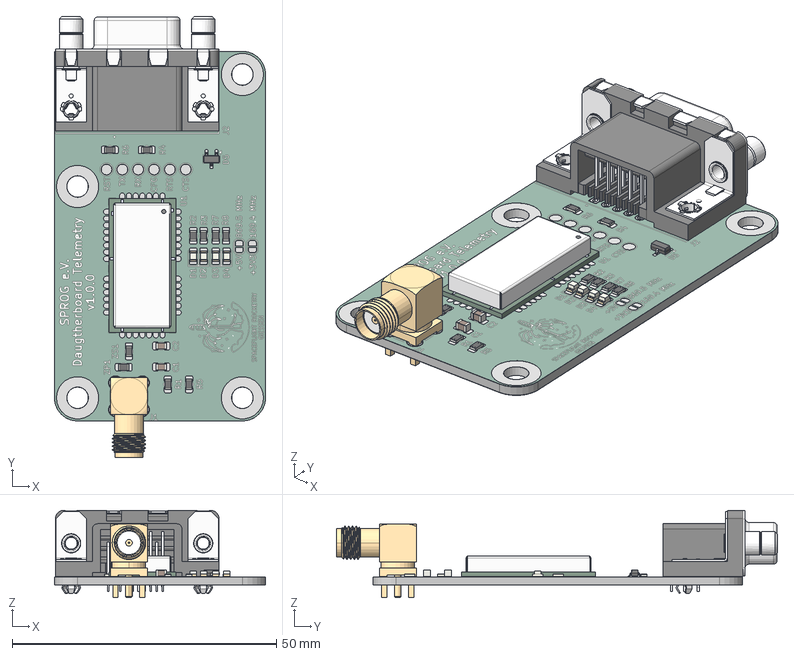
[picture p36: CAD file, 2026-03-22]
groundstation/pcb/Daughterboard/TelemetryGroundstationDB.step
40.0 x 83.5 x 16.6 mm
LED_0805_2012Metric x 4
R_0805_2012Metric x 10
C_0805_2012Metric x 2
ICD15S13E4GV00LF
SOT-23-3
Radiocrafts RC1780HP-RC232
RFPC-SMA27-F--3DModel-STEP-269445
TelemetryGroundstationDB_copper
TelemetryGroundstationDB_pad
TelemetryGroundstationDB_via
TelemetryGroundstationDB_silkscreen
TelemetryGroundstationDB_soldermask
TelemetryGroundstationDB_PCB

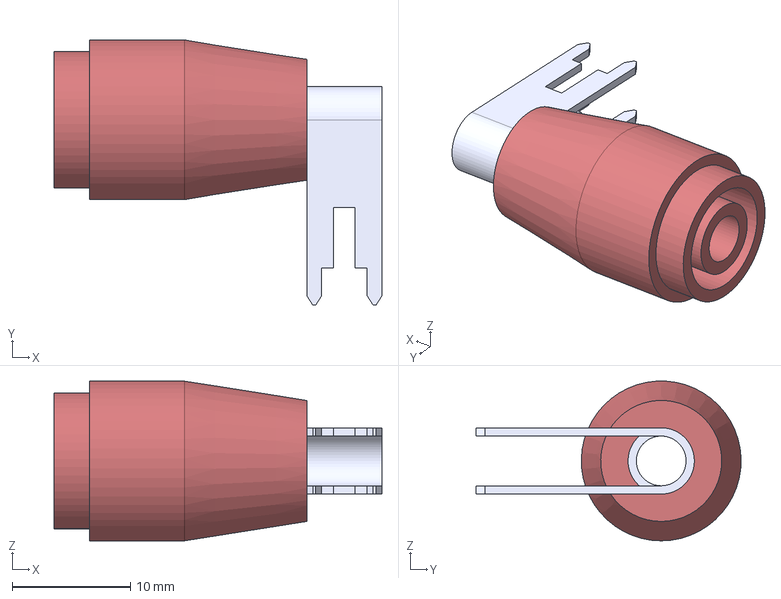
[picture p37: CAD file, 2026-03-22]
groundstation/pcb/Motherboard/3D Models/CT3151-2.step
27.7 x 22.4 x 13.5 mm

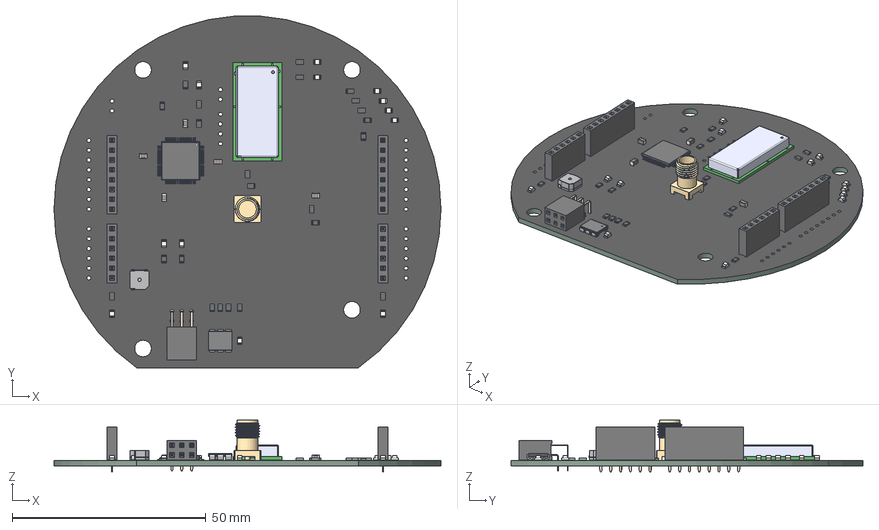
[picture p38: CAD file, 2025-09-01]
media/3dmodels/Onboard_PCB.step
100.0 x 90.9 x 13.4 mm
C_0805_2012Metric x 5
R_0805_2012Metric x 23
PinSocket_2x03_P2.54mm_Horizontal
LED_0805_2012Metric x 13
PinSocket_1x08_P2.54mm_Vertical x 2
RGB LED PLCC6_CLP6C-FKB_CRW
TQFP-64_10x10mm_P0.5mm
PinSocket_1x06_P2.54mm_Vertical x 2
Buzzer CMT-0525-75-SMT-TR
SMD Connetor CONSMA001-SMD-G-T
Radiocrafts RC1780HP-RC232
TelemetryOnboard_PCB

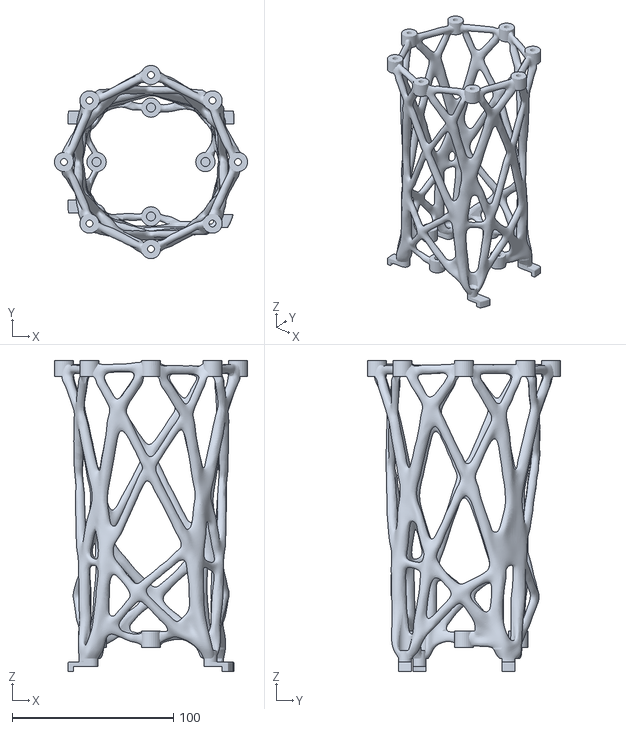
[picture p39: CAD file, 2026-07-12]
onboard/mounting structure/Auxiliary Design Files/Electronics Mounting Bracket.stl
120.0 x 120.0 x 193.0

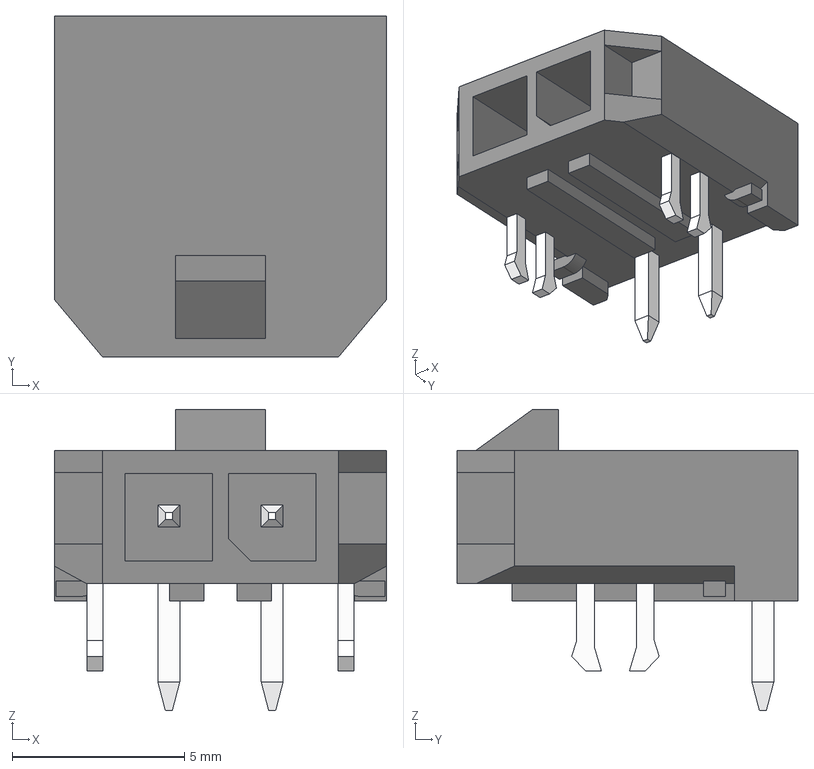
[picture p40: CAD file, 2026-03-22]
onboard/pcb/3D Models/Molex_MicroFit_2pin.stp
9.65 x 9.90 x 8.75 mm

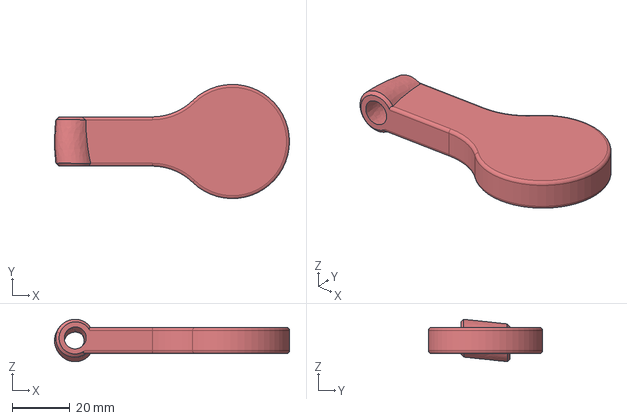
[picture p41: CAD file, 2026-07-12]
groundstation/antenna/helical/Auxiliary Design Files/Pacifier Endcap.step
81.1 x 39.4 x 14.6 mm

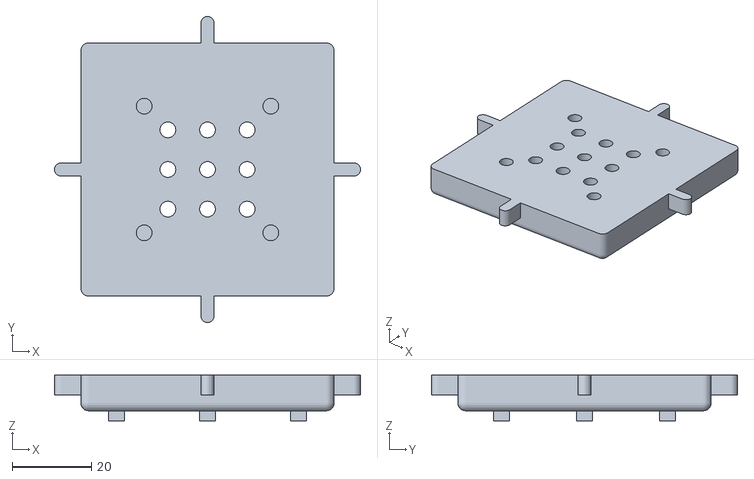
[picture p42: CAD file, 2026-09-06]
groundstation/casing/Daughterboard/Auxiliary Desing Files/deckel_bat.stl
77.3 x 77.3 x 11.5

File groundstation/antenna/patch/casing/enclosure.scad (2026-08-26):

// ===== AUTO-GENERATED by casing/enclosure.py — DO NOT hand-edit; change the Python =====
part        = "assembly";   // assembly | tray | window2d | section   (-D 'part="tray"')
board_edge=160.000; board_th=1.600; patch_w=82.500; board_r=6.000;
hole_xy=72.000; clear=1.000; wall=4.000; floor_th=4.000;
standoff_h=6.000; air_gap=10.000; window_th=3.000; ext_r=10.000;
fillet=2.000; so_od=7.000; so_pilot=2.500;
gasket_inset=1.250; gasket_w=1.500; gasket_d=1.000;
lip_w=1.500; lip_h=2.000; win_clear=0.400;
sma_d=12.000; sma_z=10.800; web_floor=7.000; zip_d=3.500;
vent=true; vent_d=6.000; vent_seat_d=14.000; vent_x=50.000; vent_y=50.000;
ear_len=12.000; ear_w=30.000; ear_hole_d=4.500;
cav=162.000; ext=170.000; board_bot=10.000; board_top=11.600;
wall_top=21.600; lip_top=23.600; window=166.200;
lip_bevel=1.000; brand_size=6.000; brand_depth=0.600;
brand_l1="SPACEFLIGHT ROCKETRY GIESSEN"; brand_l2="869.525 MHz   RHCP";
deco_on=true; deco_sz=36.000; deco_svg="../archive/corner_deco.svg";
$fn=96;

module rrect(s, r) { offset(r = r) square(s - 2 * r, center = true); }
module rprism(s, r, h) { linear_extrude(height = h) rrect(s, max(0.01, r)); }

// four board standoff bosses (nylon M3 self-taps into the boss — no metal at/above the GP)
module standoffs() {
    for (sx = [-1, 1], sy = [-1, 1])
        translate([sx * hole_xy, sy * hole_xy, floor_th])
            difference() {
                union() {
                    cylinder(d = so_od, h = standoff_h);
                    cylinder(d1 = so_od + 2 * fillet, d2 = so_od, h = fillet);   // base fillet
                }
                translate([0, 0, -0.1]) cylinder(d = so_pilot, h = standoff_h + 0.2);  // self-tap pilot bore
            }
}

// foam-gasket groove (inboard) cut into the wall top; outer land stays flat for the adhesive bond
module gasket_groove() {
    inner = cav + 2 * gasket_inset;
    outer = cav + 2 * (gasket_inset + gasket_w);
    translate([0, 0, wall_top - gasket_d])
        linear_extrude(height = gasket_d + 0.1)
            difference() { rrect(outer, ext_r); rrect(inner, ext_r); }
}

// outer locating lip the acrylic window drops into (sets the air gap by a hard ledge; drip edge).
// The OUTER face tapers in (a bezel) for a finished look; the inner pocket wall stays vertical.
module window_lip() {
    translate([0, 0, wall_top])
        difference() {
            linear_extrude(height = lip_h, scale = (ext - 2 * lip_bevel) / ext) rrect(ext, ext_r);
            translate([0, 0, -0.1]) rprism(ext - 2 * lip_w, ext_r, lip_h + 0.2);
        }
}

// coax / SMA feed-through: teardrop (bridgeable crown) with a FLAT bottom >=3 mm above the floor
module sma_cut() {
    yb = -ext / 2 - 1; len = wall + 2;
    intersection() {
        hull() {
            translate([0, yb, sma_z]) rotate([-90, 0, 0]) cylinder(d = sma_d, h = len);
            translate([0, yb, sma_z + sma_d * 0.55]) rotate([-90, 0, 0]) cylinder(d = 0.8, h = len);
        }
        translate([-sma_d, yb - 1, web_floor]) cube([2 * sma_d, len + 2, ext]);   // flat bottom
    }
    // 2x zip-tie strain-relief holes flanking the bore
    for (sx = [-1, 1])
        translate([sx * (sma_d / 2 + zip_d), yb, sma_z]) rotate([-90, 0, 0]) cylinder(d = zip_d, h = len);
}

// breather vent (floor, off-corner, behind the GP -> RF-safe): through-hole + exterior patch seat
module vent_cut() {
    if (vent) {
        translate([vent_x, vent_y, -0.1]) cylinder(d = vent_d, h = floor_th + 0.2);
        translate([vent_x, vent_y, -0.1]) cylinder(d = vent_seat_d, h = 0.8);    // exterior patch recess
    }
}

// flat mount ears on +/-X (coplanar with the floor; outside the sealed cavity). The root EMBEDS
// 'ov' mm into the wall so the ear FUSES with the body -> ONE connected first-layer footprint
// (a touching-but-not-overlapping ear slices as separate islands).
module ears() {
    ov = 4;                 // overlap into the wall (wall is 4 mm -> embeds to the cavity inner face)
    L  = ear_len + ov;
    for (sx = [-1, 1])
        translate([sx * (ext / 2 + (ear_len - ov) / 2), 0, 0])
            difference() {
                linear_extrude(floor_th) offset(r = 3) square([L - 6, ear_w - 6], center = true);
                for (sy = [-1, 1])
                    translate([sx * (L / 2 - 4.5), sy * ear_w * 0.28, -0.1])
                        cylinder(d = ear_hole_d, h = floor_th + 0.2);
            }
}

// debossed branding on the +Y outer wall (two lines) — exterior only, shallow, watertight-safe.
// mirror() in X so it reads correctly when viewed from outside (+Y, looking -Y).
module branding() {
    zs = [[brand_l1, wall_top * 0.60], [brand_l2, wall_top * 0.34]];
    for (i = [0:1])
        translate([0, ext / 2 + 0.1, zs[i][1]])
            rotate([90, 0, 0])
                linear_extrude(height = brand_depth + 0.2)
                    mirror([1, 0, 0])
                        text(zs[i][0], size = brand_size, halign = "center", valign = "center",
                             font = "Liberation Sans:style=Bold");
}

// debossed sunburst (archive/corner_deco.svg) on the +X outer wall (faces +X, cuts -X into the wall)
module deco() {
    if (deco_on)
        translate([ext / 2 - brand_depth, 0, wall_top * 0.5])
            rotate([0, 90, 0])
                linear_extrude(height = brand_depth + 0.2)
                    resize([deco_sz, deco_sz, 0], auto = true) import(deco_svg, center = true);
}

module tray() {
    cr = max(0.01, ext_r - wall);
    difference() {
        union() {
            rprism(ext, ext_r, wall_top);
            window_lip();
            ears();
        }
        // cavity with a 45-ish inner floor/wall fillet at the base
        translate([0, 0, floor_th])
            linear_extrude(height = fillet, scale = cav / (cav - 2 * fillet)) rrect(cav - 2 * fillet, cr);
        translate([0, 0, floor_th + fillet]) rprism(cav, cr, wall_top);
        gasket_groove();
        sma_cut();
        vent_cut();
        branding();
        deco();
    }
    standoffs();
}

module window3d() { translate([0, 0, wall_top]) rprism(window, ext_r, window_th); }
module window2d() { rrect(window, ext_r); }   // undersized cut outline -> DXF (lip + clearance)

module board_ph() {
    color([0.0, 0.45, 0.2]) translate([0, 0, board_bot]) rprism(board_edge, board_r, board_th);
    color([0.85, 0.65, 0.1]) translate([0, 0, board_top]) rprism(patch_w, 6, 0.4);
}

module assembly() {
    tray();
    board_ph();
    color([0.6, 0.8, 1.0, 0.35]) window3d();
}

module section() {
    difference() {
        assembly();
        translate([-ext, 0, -60]) cube([2 * ext, 2 * ext, 220]);   // clean half-space: remove y>0
    }
}

if (part == "assembly") assembly();
else if (part == "tray") tray();
else if (part == "window2d") window2d();
else if (part == "section") section();

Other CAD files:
groundstation/casing/Motherboard/Auxiliary Design Files/Casing Bottom.step
groundstation/pcb/Daughterboard/3D Models/RFPC-SMA27-F--3DModel-STEP-269445.STEP
groundstation/pcb/Motherboard/3D Models/LD09S33E4GV00LF.step
groundstation/antenna/helical/Auxiliary Design Files/Pacifier Fixture.step
groundstation/antenna/helical/Auxiliary Design Files/Bottom Cone.step
groundstation/antenna/helical/Auxiliary Design Files/Bottom Cone.stl
groundstation/antenna/helical/Auxiliary Design Files/Pacifier Endcap.stl
groundstation/antenna/helical/Auxiliary Design Files/Pacifier Fixture.stl
groundstation/antenna/helical/Auxiliary Design Files/Pacifier.step
groundstation/antenna/helical/Auxiliary Design Files/Pacifier.stl
groundstation/antenna/helical/Auxiliary Design Files/Top Cone.step
groundstation/antenna/helical/Auxiliary Design Files/Top Cone.stl
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

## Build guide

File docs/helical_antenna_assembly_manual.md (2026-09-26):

# Helical Antenna Build Manual

This document describes how we built our helical groundstation antenna for receiving telemetry from our rockets. 

The images were taken during the build of the much larger older version of the antenna but also apply to the updated small version.

---

## Table of Contents

- [Overview](#overview)
- [Bill of Materials](#bill-of-materials)
  - [3D-Printed Design Files](#3d-printed-design-files)
- [Build Process](#build-process)
  - [Phase 1 - Rod Preparation \& Pacifier Placement](#phase-1---rod-preparation--pacifier-placement)
  - [Phase 2 - Epoxy Application](#phase-2---epoxy-application)
  - [Phase 3 - Winding the Helical Coil](#phase-3---winding-the-helical-coil)
  - [Phase 4 - Inserting the Coil](#phase-4---inserting-the-coil)
  - [Phase 5 - Base Plate \& Final Assembly](#phase-5---base-plate--final-assembly)
  - [Phase 6 - Soldering](#phase-6---soldering)
- [Build Checklist](#build-checklist)

---

## Overview

The mechanical design of the helical antenna is explained in the [design overview](design_overview.md#mechanical-design).

|Side View | Base Detail|
|---|---|

---

## Bill of Materials

|Item|Specification|Est. Cost (€)|
|---|---|:---:|
|Fiberglass Rod|1 m length, 31 mm diameter|20|
|Aluminum Plate|40 × 40 cm, 1.5 mm thickness|15|
|Copper Tube|5 m length, 6 mm diameter, hollow|30|
|[SMA Connector](https://www.digikey.de/de/products/detail/te-connectivity-linx/CONSMA016-15-G/11624645)|WR-SMA Panel 4-Hole Flange|7|
|[Pacifier](../groundstation/antenna/helical/Auxiliary%20Design%20Files/Pacifier.stl)|7x (3D printed)|-|
|[Pacifier Endcap](../groundstation/antenna/helical/Auxiliary%20Design%20Files/Pacifier%20Endcap.stl)|1 (3D printed)|-|
|[Pacifier Fixture](../groundstation/antenna/helical/Auxiliary%20Design%20Files/Pacifier%20Fixture.stl)|1× (3D printed)|-|
|[Cone Top](../groundstation/antenna/helical/Auxiliary%20Design%20Files/Top%20Cone.stl)|1× (3D printed)|-|
|[Cone Bottom](../groundstation/antenna/helical/Auxiliary%20Design%20Files/Bottom%20Cone.stl)|1× (3D printed)|-|
|[Winding Clamp](../groundstation/antenna/helical/Auxiliary%20Design%20Files/Winding%20Clamp.stl)|3× (3D printed)|-|
|[Winding Help](../groundstation/antenna/helical/Auxiliary%20Design%20Files/Winding%20Help.stl)|1× (3D printed)|-|
|[Drilling Template](../groundstation/antenna/helical/drilling_template.pdf)|1× (printed)|-|
|M6 × 25 Screws|6×|-|
|M6 Nuts|6×|-|
|M2.5 × 10 Screws|4×|-|
|M2.5 Nuts|4×|-|
|Epoxy Resin + Hardener|with syringes and mixing equipment|10|
|Hot Glue Sticks|for temporary fixturing|-|
|Isopropyl Alcohol|for surface cleaning|-|
|String / Guy Wire| for structural bracing, non metallic|5|
|**Total (excl. 3D printing)**||**87**|

### 3D-Printed Design Files

All 3D models are available in the [`groundstation/antenna/helical/`](../groundstation/antenna/helical/) subfolder:

- Original Design Files: Native `.f3z` / `.f3d` Autodesk Fusion files
- Auxiliary Design Files: Parts exported as `.stl` and `.step`

---

## Build Process

### Phase 1 - Rod Preparation & Pacifier Placement

**1. The pacifiers**

The "pacifiers" are 3D-printed ring fixtures that hold the copper coil at the correct spacing and angle along the fiberglass rod. They are the most integral part of the assembly since they decide the final geometry.

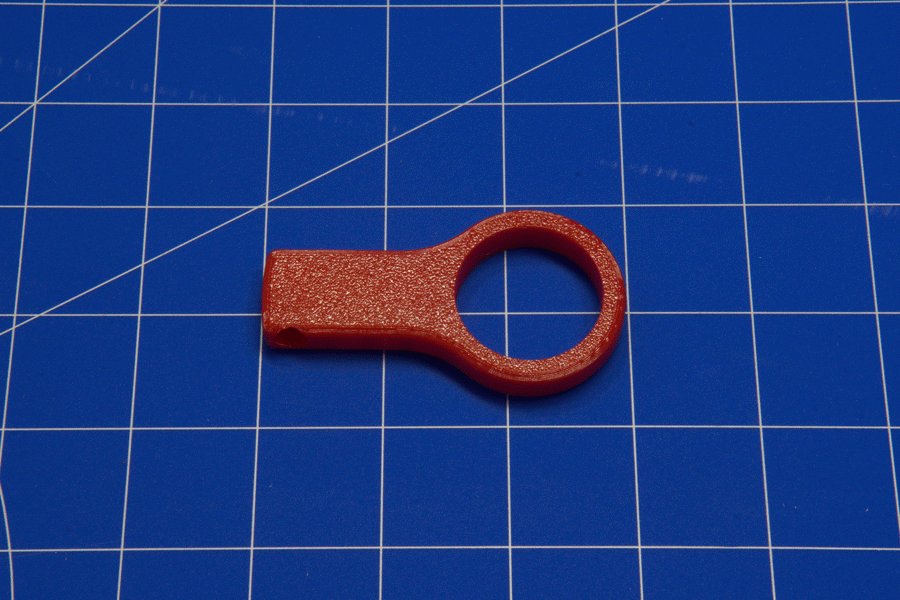
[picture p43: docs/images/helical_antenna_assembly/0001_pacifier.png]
Pacifier part
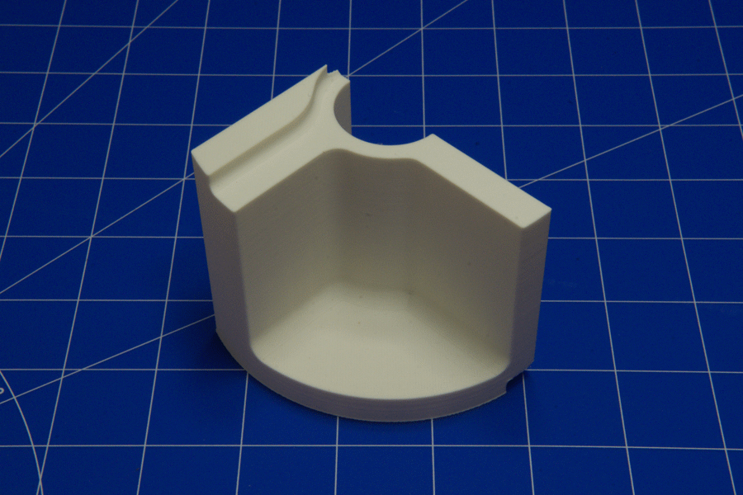
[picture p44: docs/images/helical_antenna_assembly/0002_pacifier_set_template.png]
Template placement
||||
|---|---|---|
|[Pacifier](../groundstation/antenna/helical/Auxiliary%20Design%20Files/Pacifier.stl)|[Pacifier Endcap](../groundstation/antenna/helical/Auxiliary%20Design%20Files/Pacifier%20Endcap.stl)|[Pacifier Spacer](../groundstation/antenna/helical/Auxiliary%20Design%20Files/Pacifier%20Fixture.stl)|

<p align="center">
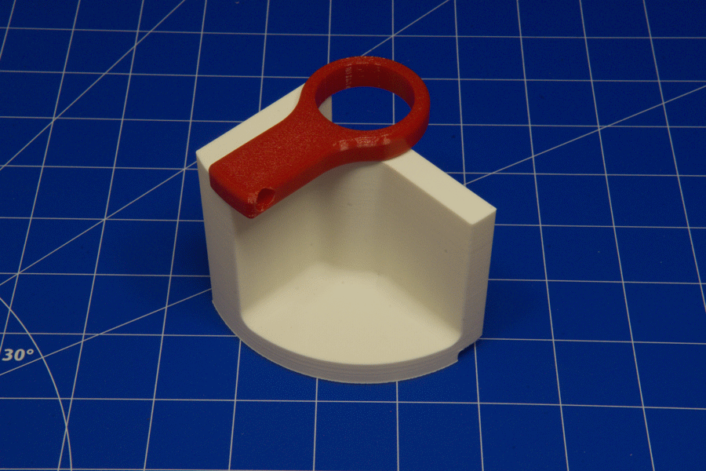
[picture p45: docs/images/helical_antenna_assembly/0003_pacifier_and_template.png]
Pacifier and template
  
</p>

**2. Prepare the rod**

Lay the fiberglass rod on your work surface and clean it thoroughly with isopropyl alcohol.

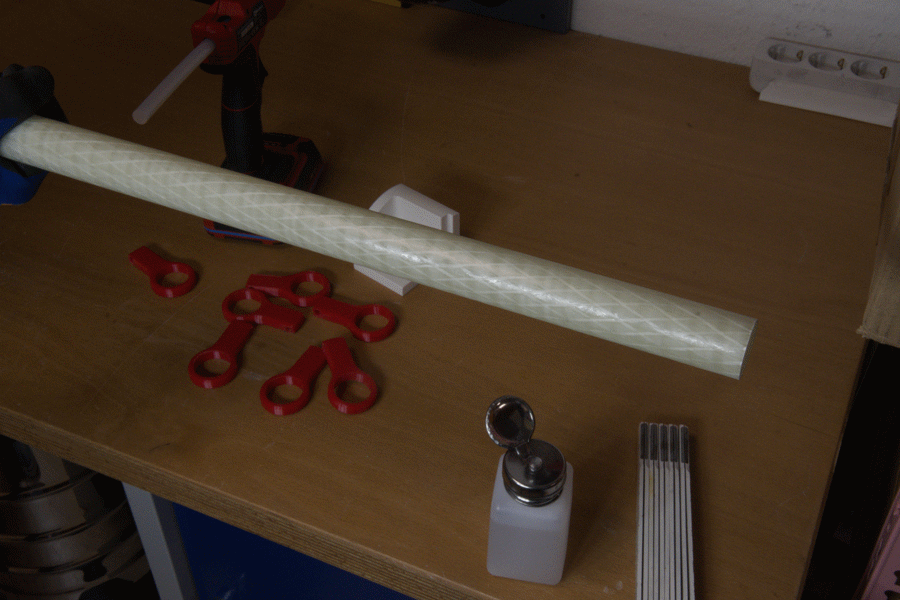
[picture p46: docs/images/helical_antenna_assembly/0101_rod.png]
Rod
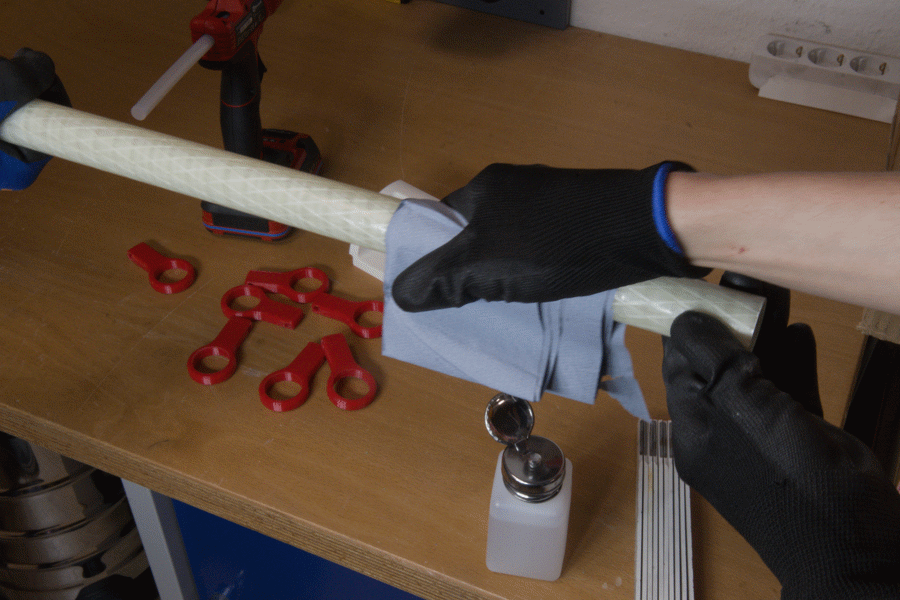
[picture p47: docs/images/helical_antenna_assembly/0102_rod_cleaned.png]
Cleaned rod
|||
|---|---|

**3. Set the endcap pacifier**

Place the endcap pacifier at the top of the rod and attach it with hot glue in the inside. You will work your way down from the top.

**4. Attach with hot glue**

Using the 3D-printed pacifier spacer, position and hot-glue each pacifier. Apply a small amount first, just enough for initial stability. Wait for the glue to partially cure, remove the template, then add more hot glue around the perimeter of the pacifier. Rotate the entire assembly slowly for a few seconds while the glue cools to prevent it from sagging or setting off-axis.

Cooling can be accelerated with compressed air or a fan. Our compressor had issues on build day, so we had to cool it the old-fashioned way - by blowing on a long rod for several hours. Highly recommended workout for the lungs.

Repeat for all pacifiers down the rod.

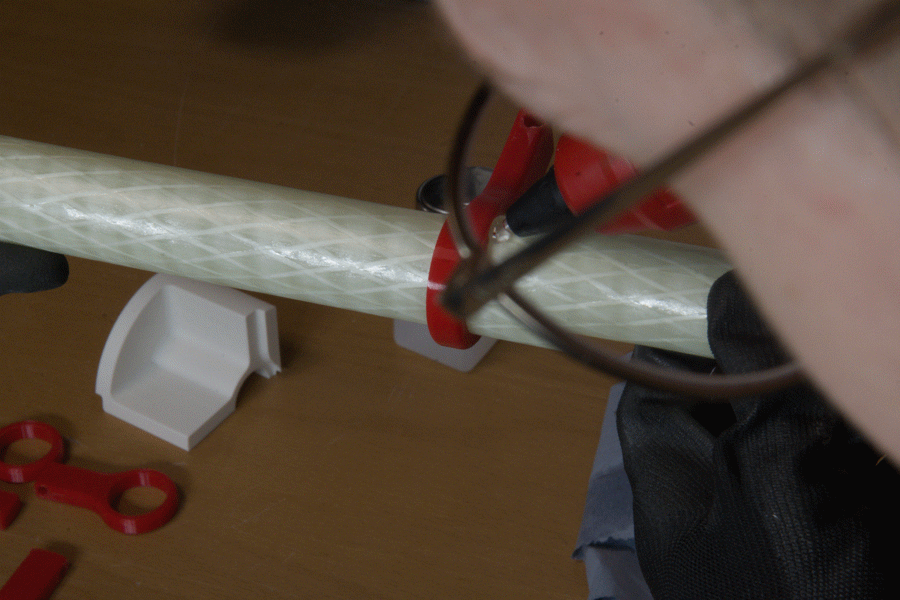
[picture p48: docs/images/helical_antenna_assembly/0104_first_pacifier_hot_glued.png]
Hot glued
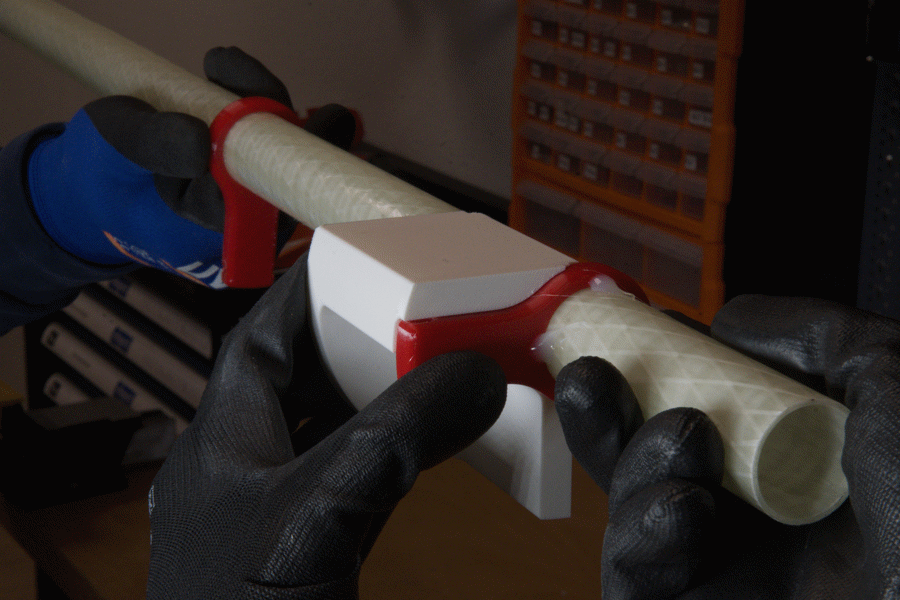
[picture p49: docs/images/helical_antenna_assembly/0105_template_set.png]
Template set
|||
|---|---|
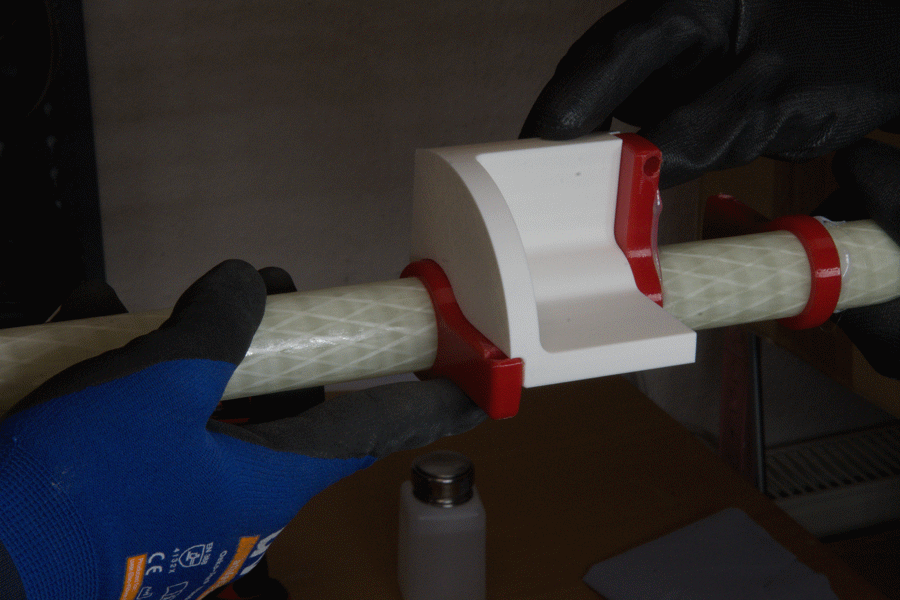
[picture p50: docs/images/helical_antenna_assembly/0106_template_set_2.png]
Template set 2
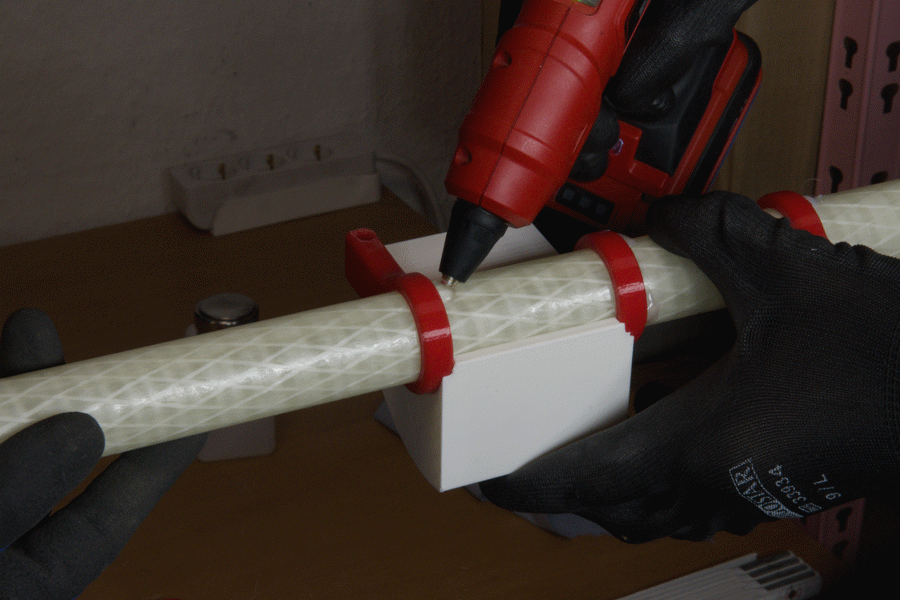
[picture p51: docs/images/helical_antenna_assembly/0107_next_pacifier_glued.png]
Next pacifier glued
| ||

The result should look like this:

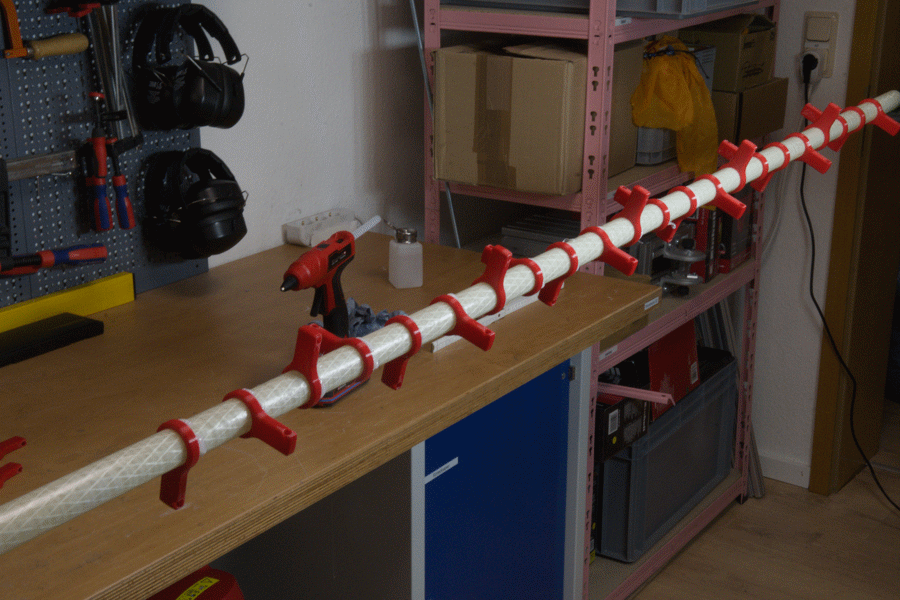
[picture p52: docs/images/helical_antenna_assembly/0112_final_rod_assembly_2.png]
Final rod assembly 2
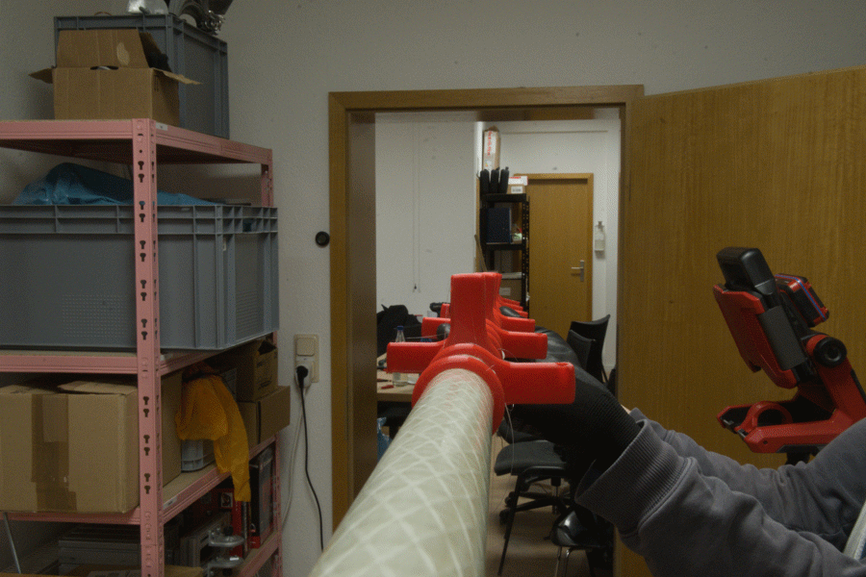
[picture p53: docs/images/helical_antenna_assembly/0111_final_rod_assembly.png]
Final rod assembly
|||
|---|---|

Due to 3D printing tolerances, the template may introduce a small angular offset between pacifiers. This is minor and acceptable.

---

### Phase 2 - Epoxy Application

Always wear a respirator mask and eye protection and open the windows when working with epoxy resin. A helmet is advised for the looks.

<p align="center">
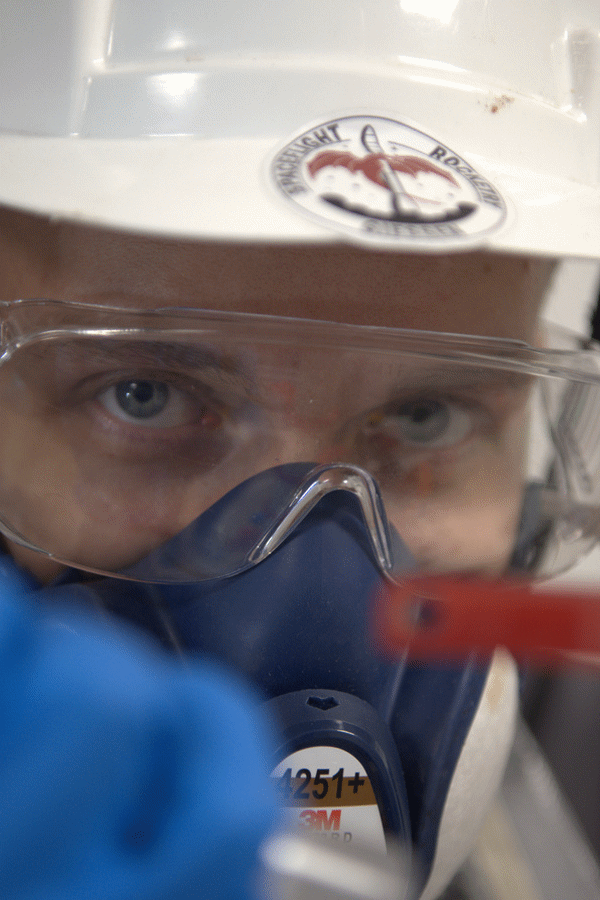
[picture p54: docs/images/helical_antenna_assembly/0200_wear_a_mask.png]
Wear a mask
  
</p>

**1. Mount for curing**

Attach one spare pacifier to the topmost part of the rod and hang the assembly from a shelf so the epoxy can be applied and cure fully upright, without placing stress on any of the pacifiers.

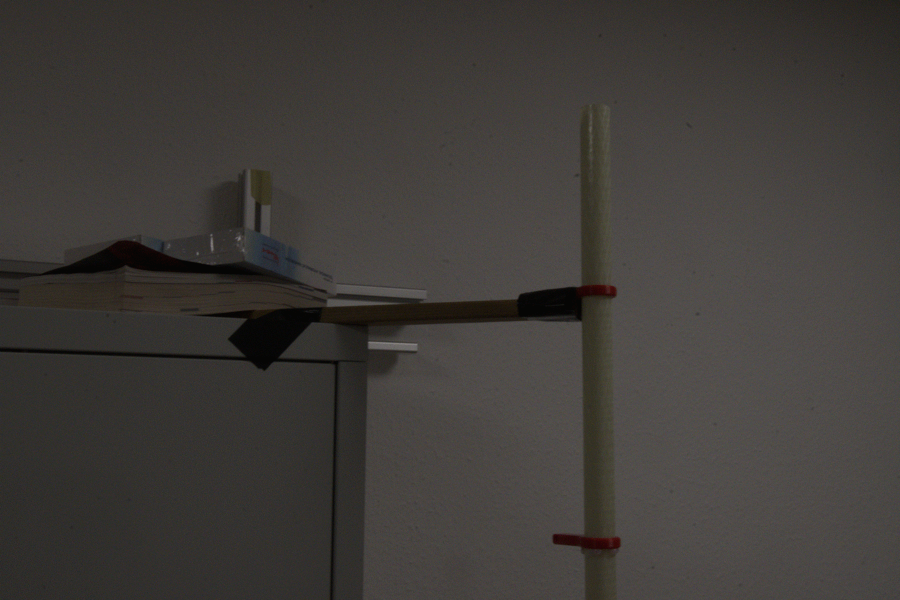
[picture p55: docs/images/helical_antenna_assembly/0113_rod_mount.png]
Shelf attachment
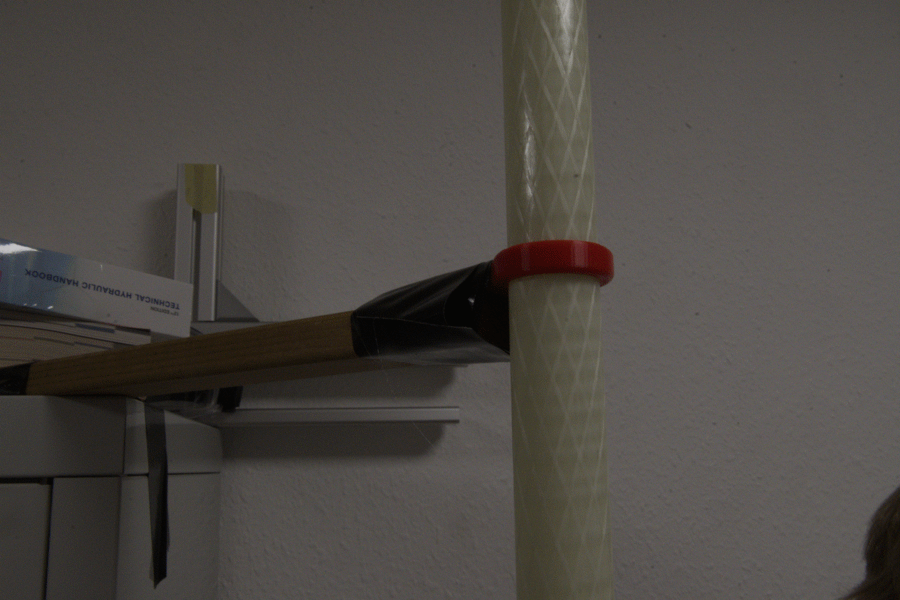
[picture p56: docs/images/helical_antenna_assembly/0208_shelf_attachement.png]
Shelf attachment 2
|||
|---|---|

**2. Mix and draw up epoxy**

Mix the two-part epoxy resin according to the manufacturer's instructions. Draw it into syringes with large blunt-tip needles for controlled application.

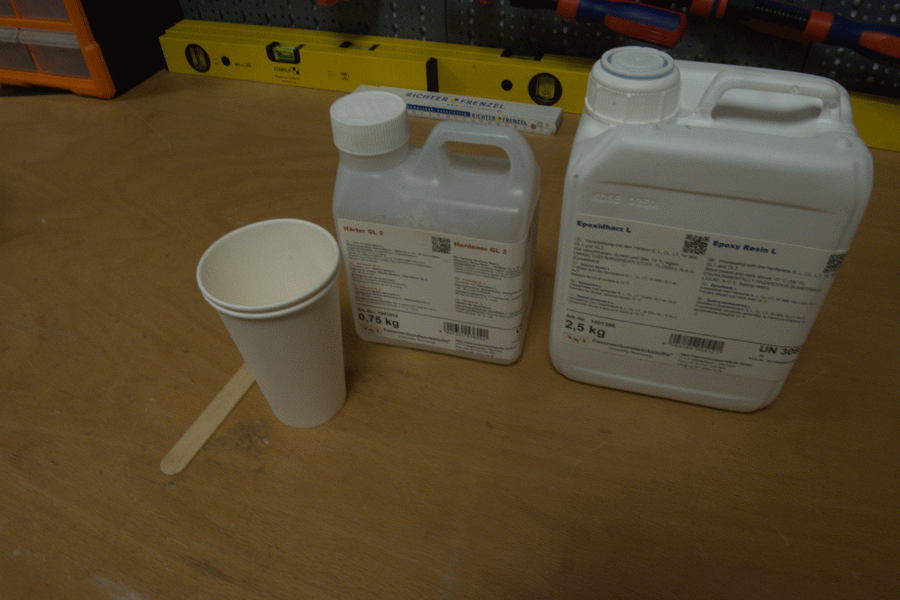
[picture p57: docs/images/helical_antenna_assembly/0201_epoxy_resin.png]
Epoxy resin
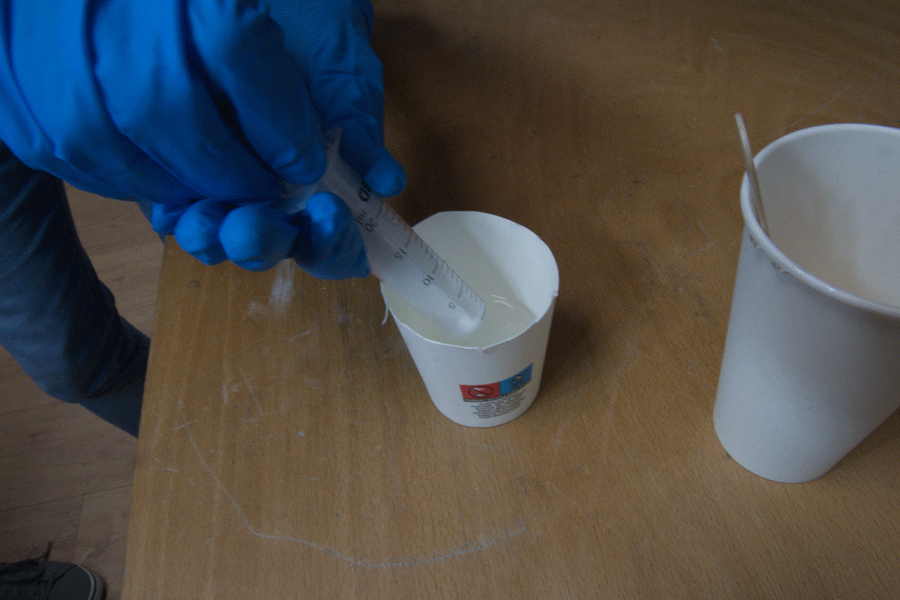
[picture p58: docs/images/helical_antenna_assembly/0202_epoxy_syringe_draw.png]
Drawing epoxy into syringe
|||
|---|---|

**3. First application - top side of rings**

Turn the rod upside down. Apply epoxy to the top face of each pacifier-to-rod junction. The bottom face is still covered by hot glue at this point, so leave it.

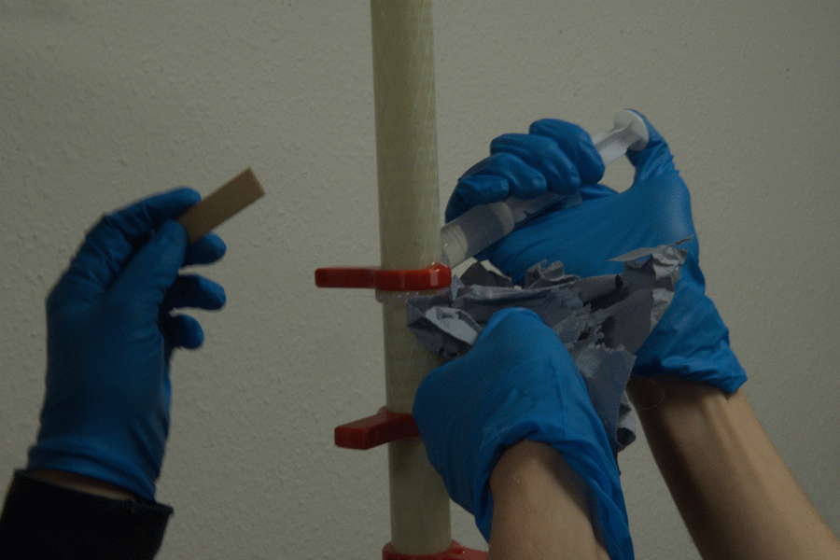
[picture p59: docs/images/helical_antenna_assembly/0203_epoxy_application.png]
Epoxy application
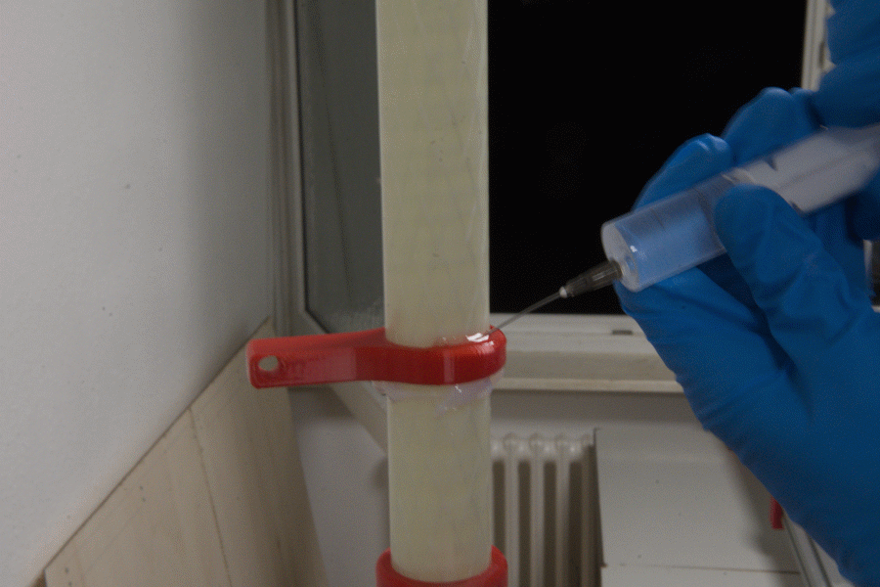
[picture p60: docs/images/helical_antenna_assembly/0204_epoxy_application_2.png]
Epoxy application 2
|||
|---|---|
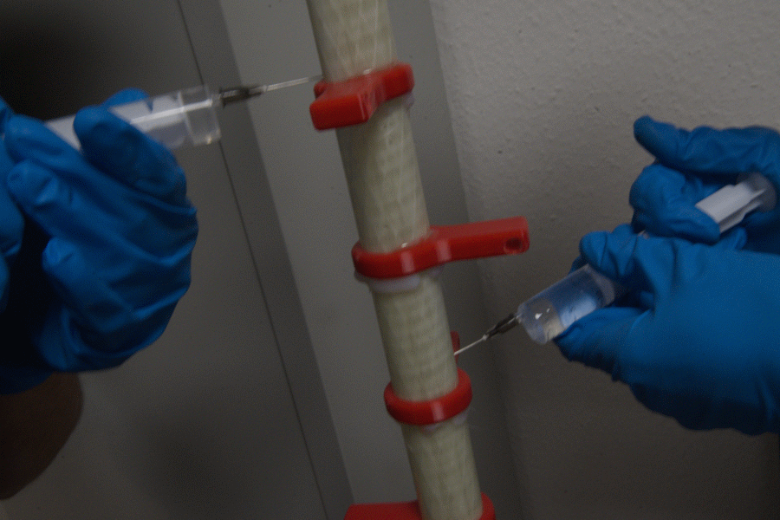
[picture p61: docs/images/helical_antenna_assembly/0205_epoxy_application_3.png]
Epoxy application 3
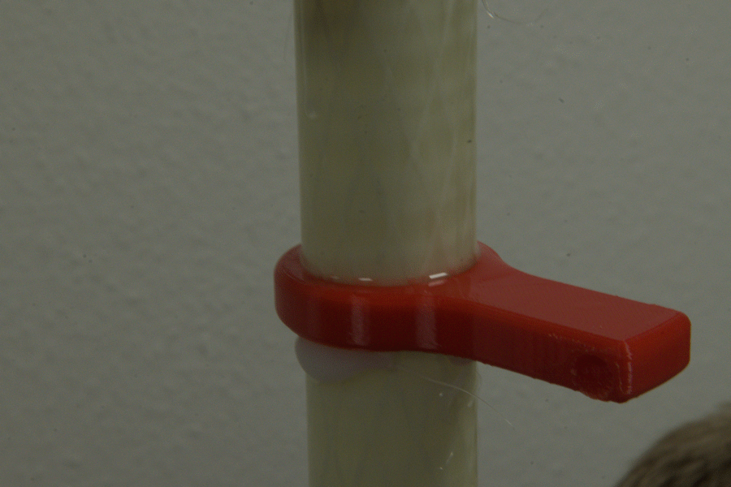
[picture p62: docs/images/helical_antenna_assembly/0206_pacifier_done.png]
Pacifier done
|||

The epoxy may wick into small gaps between the pacifier and the rod which should increase the bonding strength. However, drips are undesired and hould be wiped with acetone.

**4. Second application - bottom side of rings**

Remove the rod from the shelf fixture, turn it around and reinsert it in the fixture. 

Remove the hot glue, then apply epoxy to the previously covered bottom faces of each pacifier.

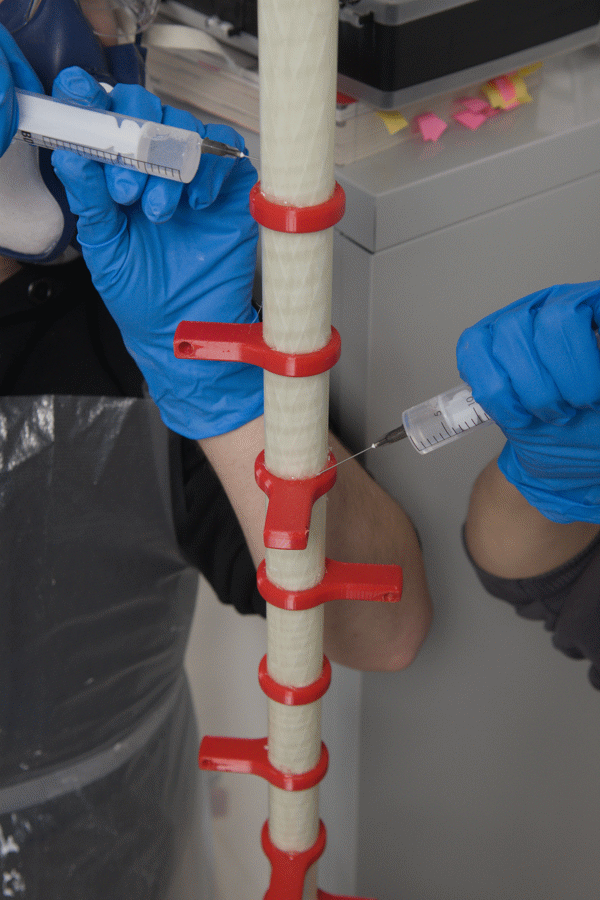
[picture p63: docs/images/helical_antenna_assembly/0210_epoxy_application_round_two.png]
Round two
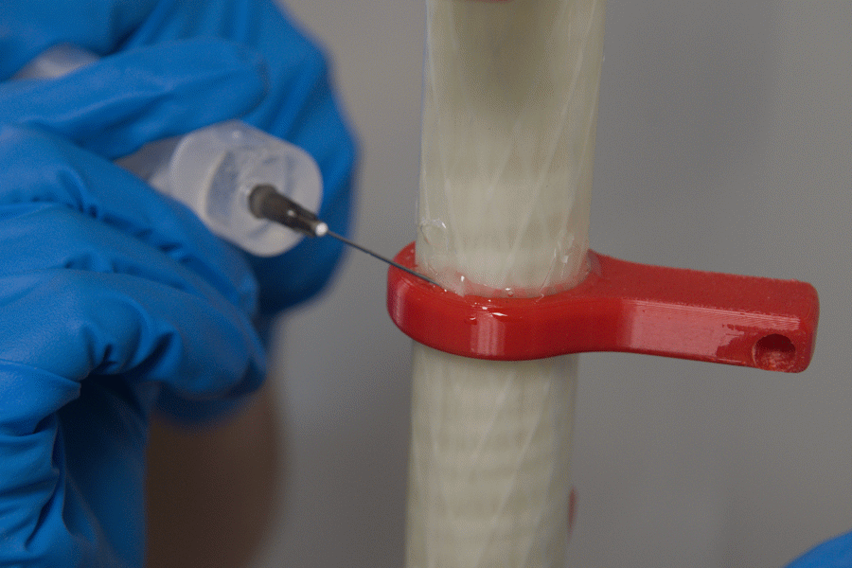
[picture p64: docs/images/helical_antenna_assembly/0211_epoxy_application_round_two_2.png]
Round two 2
|  |  |
|---|---|

Allow to cure fully before proceeding.

---

### Phase 3 - Winding the Helical Coil

**1. The winding template**

Use the 3D-printed winding help form to shape the copper tube into the correct helix diameter. Printed winding clamps hold the tube against the form, secured with woodworking clamps.

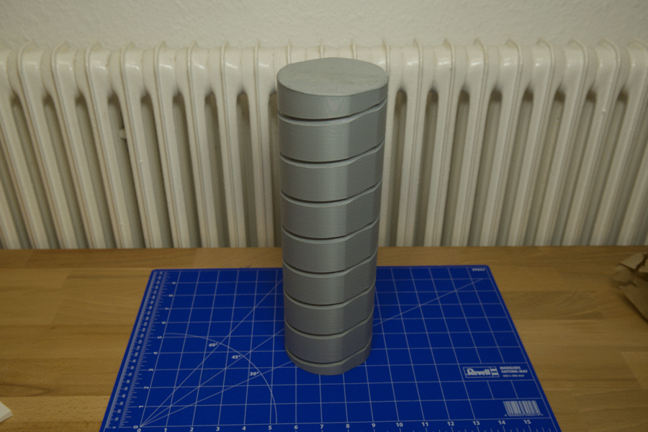
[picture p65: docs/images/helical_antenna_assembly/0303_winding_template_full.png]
Full template
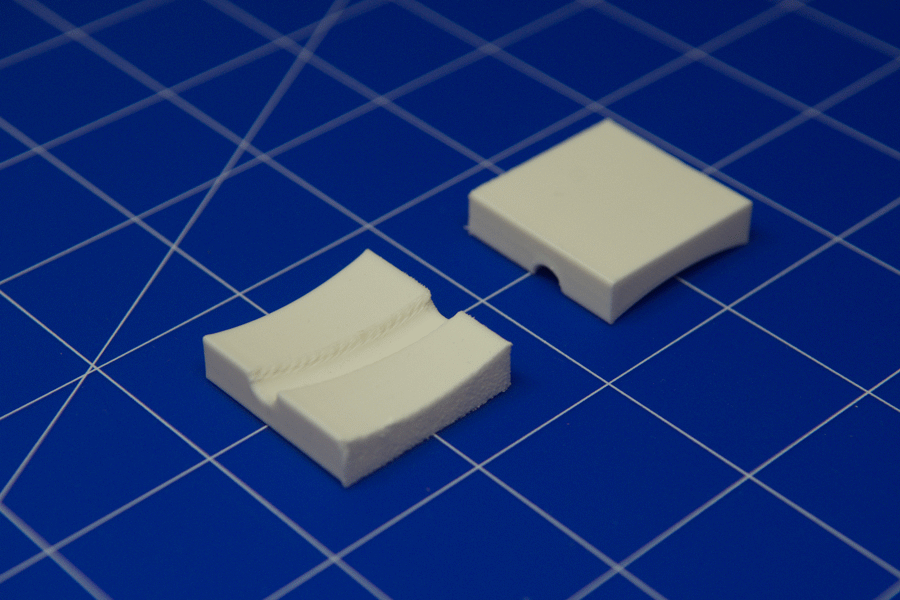
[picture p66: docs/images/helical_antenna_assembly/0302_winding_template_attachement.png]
Template attachment
|||
|---|---|
|[Winding Help](../groundstation/antenna/helical/Auxiliary%20Design%20Files/Winding%20Help.stl)|[Winding Clamp](../groundstation/antenna/helical/Auxiliary%20Design%20Files/Winding%20Clamp.stl)|

**2. Wind the coil**

With the tube clamped to the template, rotate it around the mandrel in a continuous helical motion, and secure it after each turn with a clamp. The copper tube should more or less keep its shape.

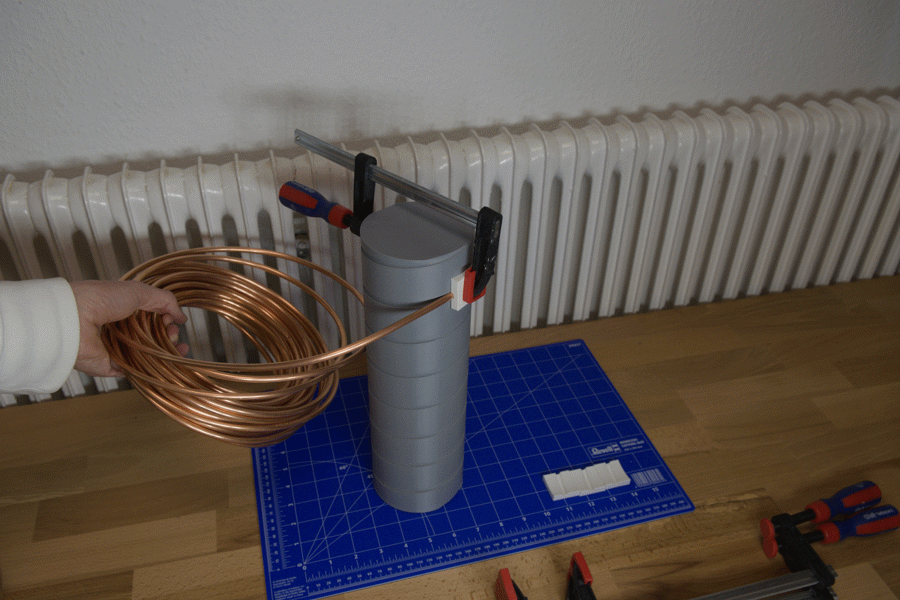
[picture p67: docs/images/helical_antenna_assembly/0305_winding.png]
Winding 1
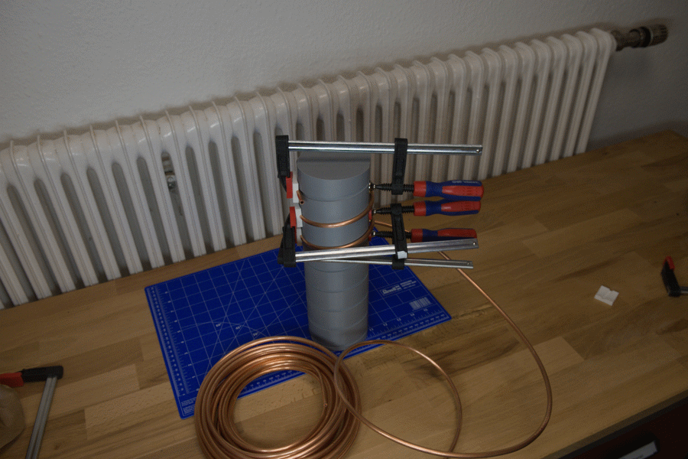
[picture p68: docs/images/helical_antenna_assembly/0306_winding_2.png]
Winding 2
|||
|---|---|
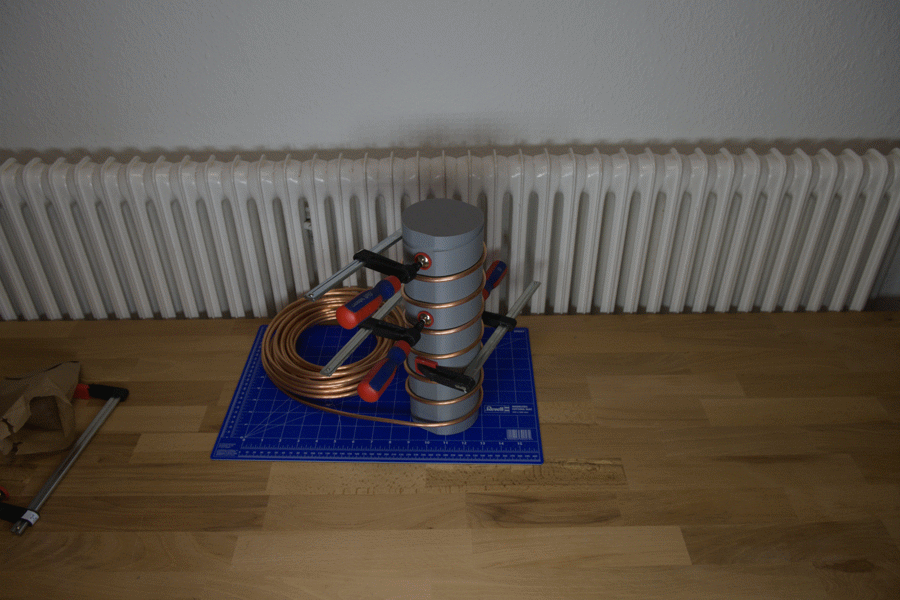
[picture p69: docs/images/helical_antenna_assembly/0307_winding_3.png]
Winding 3
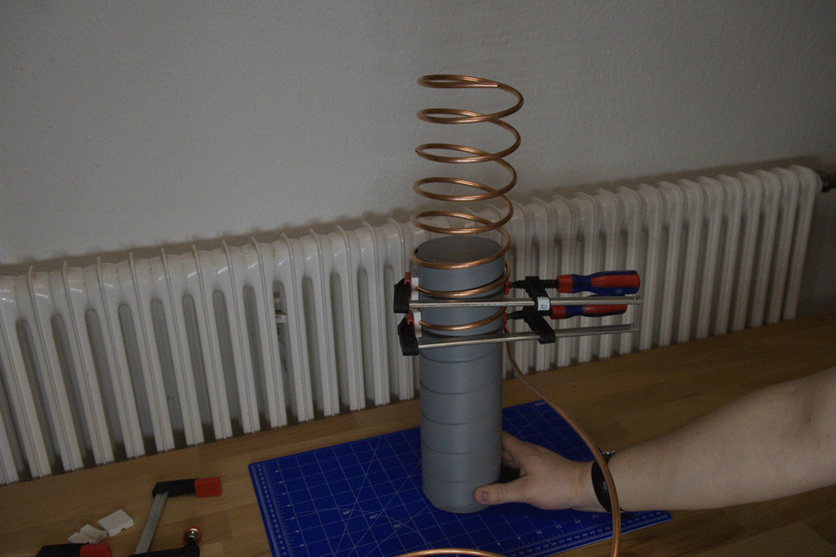
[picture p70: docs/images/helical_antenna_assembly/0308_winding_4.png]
Winding 4
|||

The coil may not seem be perfectly straight due to its springy behaviour, but this does not affect function since it will be hold by the pacifiers.

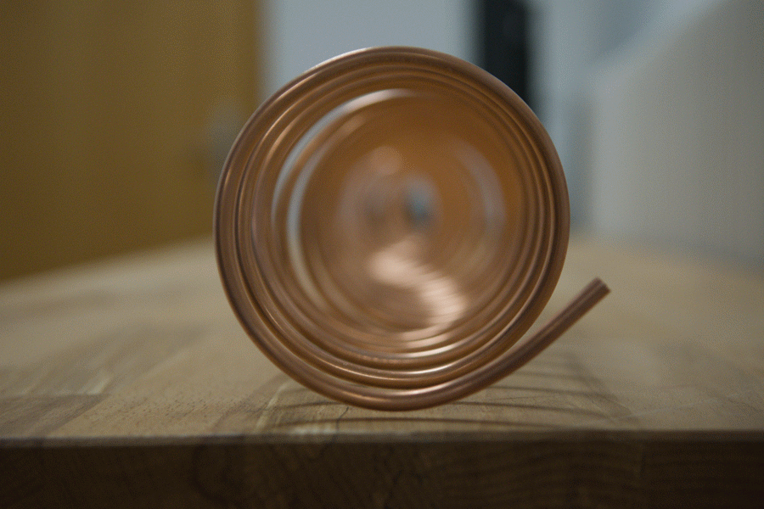
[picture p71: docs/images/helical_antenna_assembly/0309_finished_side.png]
Finished side
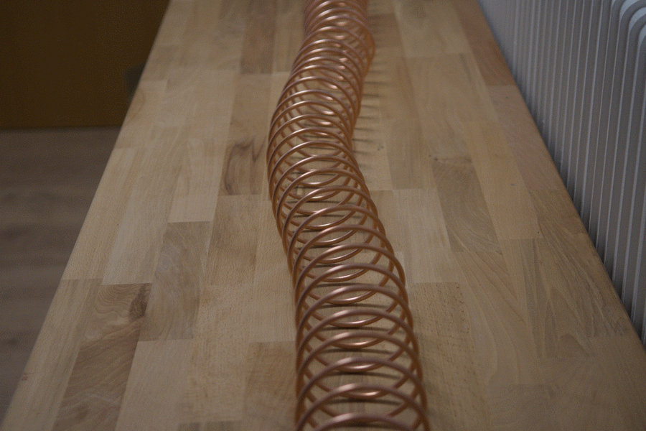
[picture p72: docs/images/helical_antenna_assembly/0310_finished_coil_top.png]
Finished coil top
|||
|---|---|

<p align="center">
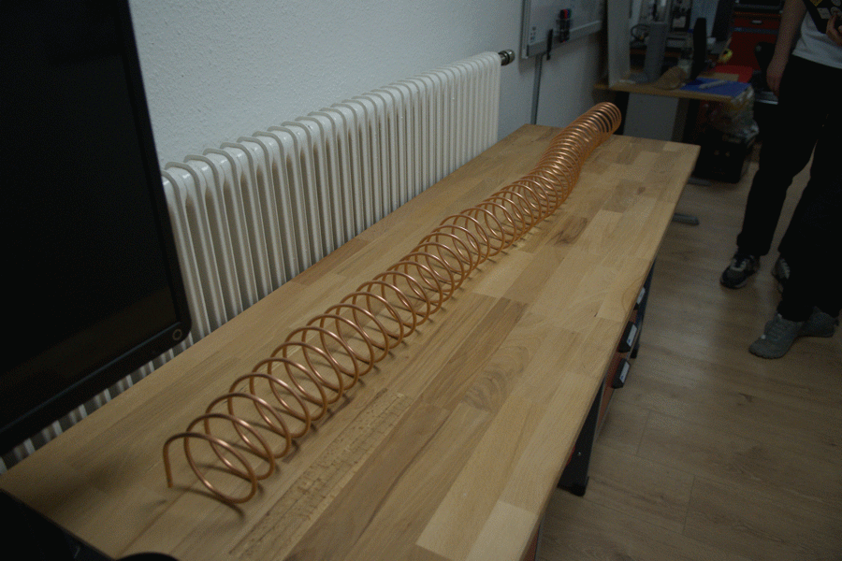
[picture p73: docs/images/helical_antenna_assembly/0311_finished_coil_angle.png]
Finished coil angle
  
</p>
---

### Phase 4 - Inserting the Coil

**1. Insert the coil into the pacfifiers**

Insert the finished coil into the pacifier assembly on the rod with a smooth rotating motion.

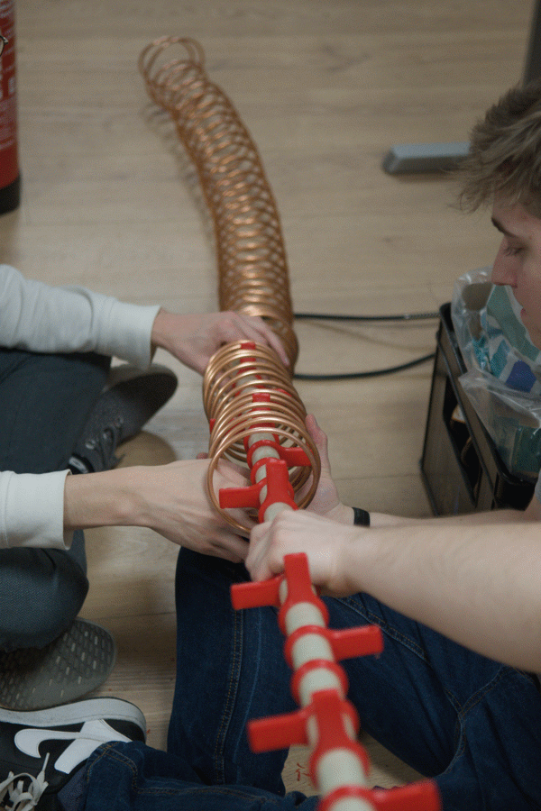
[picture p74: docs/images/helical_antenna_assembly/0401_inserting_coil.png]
Inserting coil
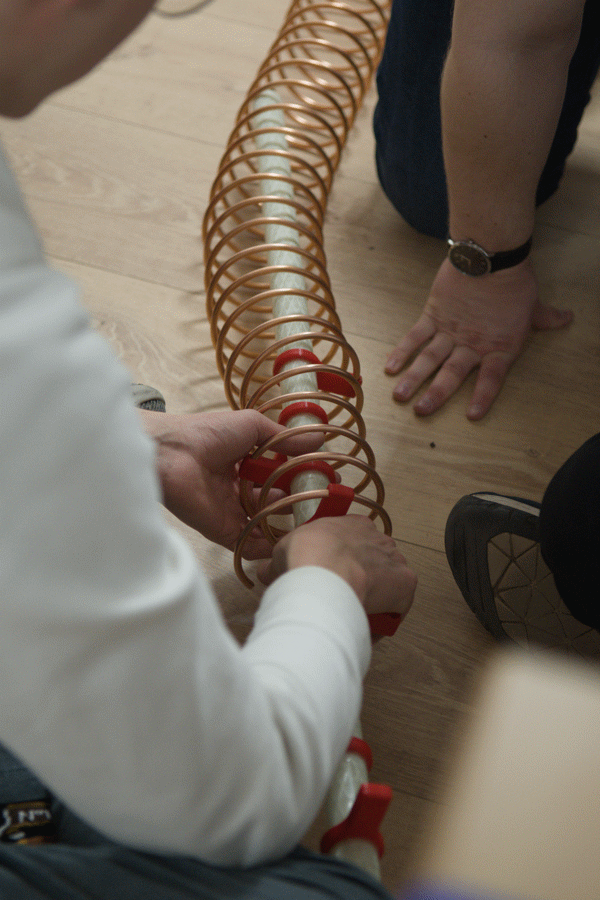
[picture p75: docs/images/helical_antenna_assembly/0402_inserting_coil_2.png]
Inserting coil 2
|||
|---|---|

This step is very easy and should take about 5 minutes.

**2. Trim the coil**

Once fully seated, trim the copper tube flush at the last pacifier. This can be done with a small multitool or a metal saw

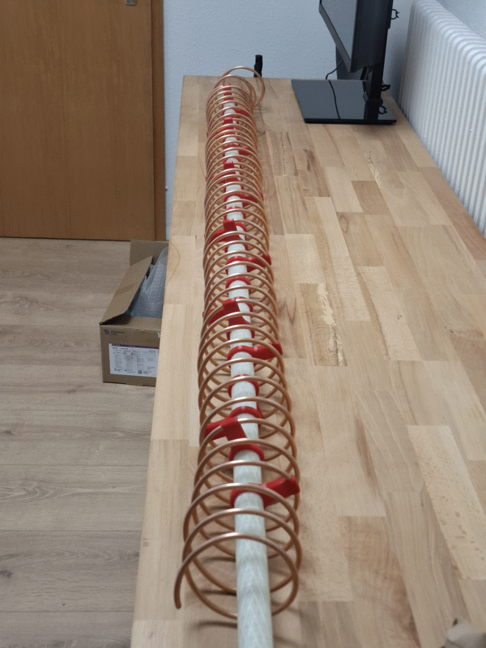
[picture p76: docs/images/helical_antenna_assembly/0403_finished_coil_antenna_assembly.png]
Finished coil antenna assembly
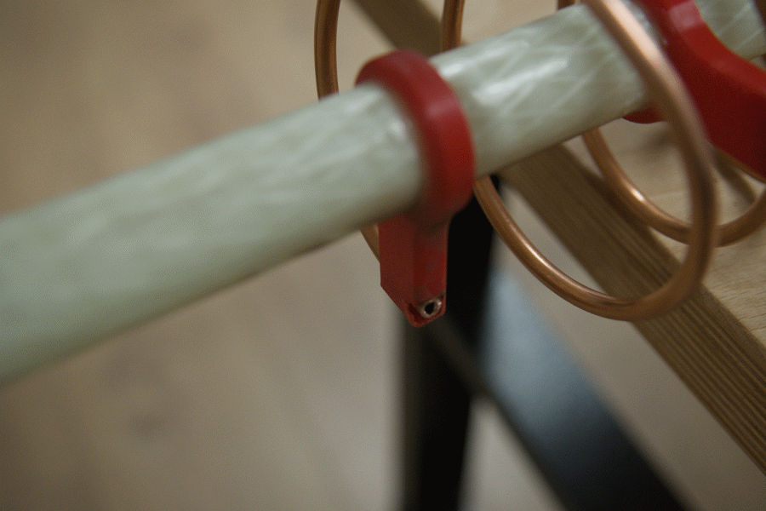
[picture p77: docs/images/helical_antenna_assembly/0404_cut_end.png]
Cut end
|||
|---|---|

**3. Bend the end straight**

Bend the end of the tube straight towards the groundplane.

---

### Phase 5 - Base Plate & Final Assembly

**1. Prepare the aluminum ground plane**

Drill a center hole through the aluminum plate sized to pass the fiberglass rod. Around it, drill holes for the cone mounting screws (M6). Add holes for the SMA connector (M2.5). The [included drilling template](../groundstation/antenna/helical/drilling_template.pdf) can be used: print it and stick it on the plate with adhesive.

This is also a good time to drill the corner holes for the guy-wire string attachment, while the plate is already on the drill press.

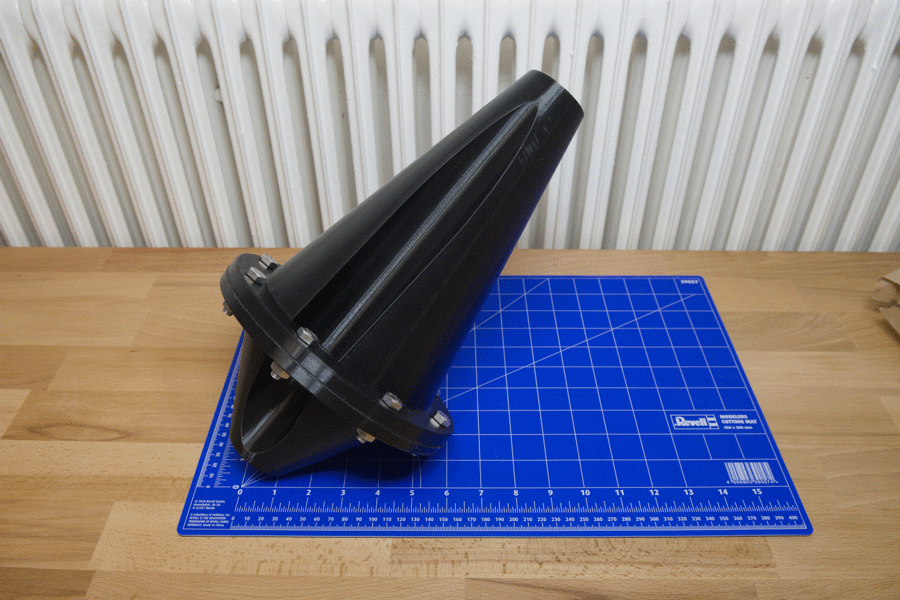
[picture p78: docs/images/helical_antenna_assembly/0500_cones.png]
Cones
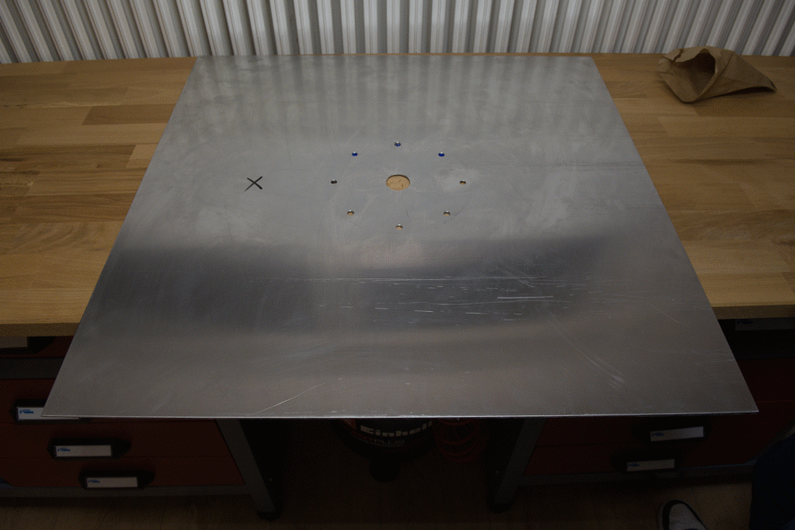
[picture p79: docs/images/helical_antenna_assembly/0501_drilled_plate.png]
Drilled plate
|||
|---|---|

**2. Assemble the cones and connector**

Install the SMA connector using the M2.5 screws. Pass the SMA conenctor from the Antenna side in, so it can be disassembled afterward.  Mount the [Top Cone](../groundstation/antenna/helical/Auxiliary%20Design%20Files/Top%20Cone.stl) from above and bolt it down with the M6 screws. Finally, attach the [Bottom Cone](../groundstation/antenna/helical/Auxiliary%20Design%20Files/Bottom%20Cone.stl) from below, by removing the nuts from the Top Cone, and using them to bolt the Bottom Cone to the Top Cone

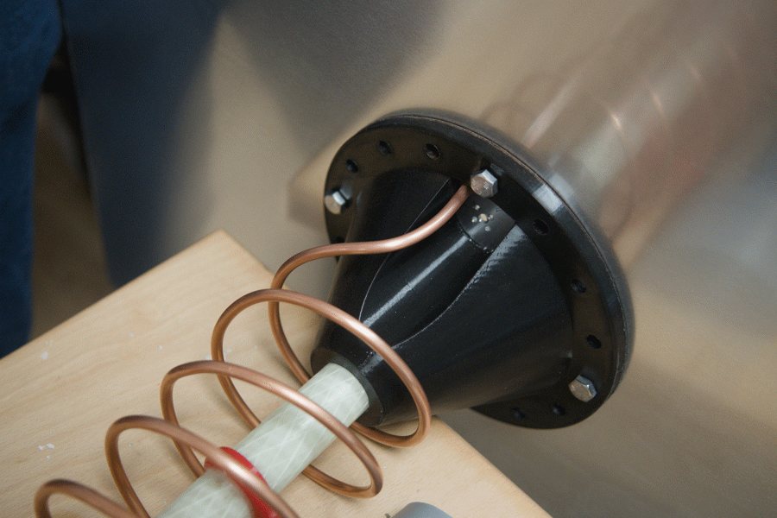
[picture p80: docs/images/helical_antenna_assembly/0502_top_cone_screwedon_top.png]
Top cone screwed on (top view)
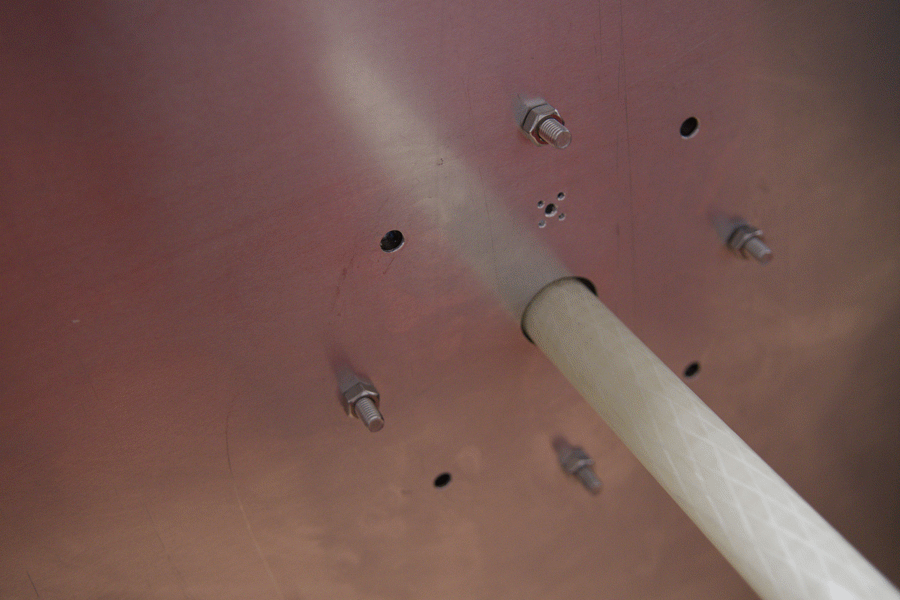
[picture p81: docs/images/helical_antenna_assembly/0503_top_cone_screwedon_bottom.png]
Top cone screwed on (bottom view)
|  |  |
| --- | --- |
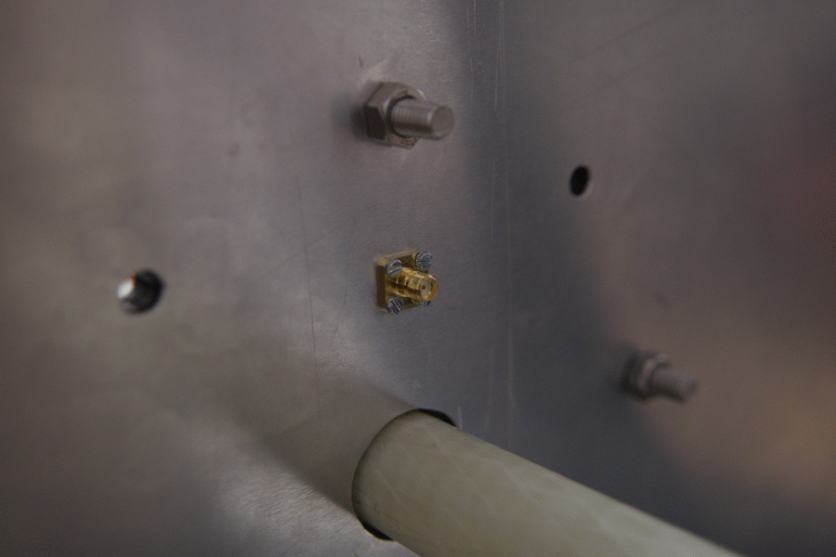
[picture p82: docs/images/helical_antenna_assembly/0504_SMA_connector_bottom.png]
SMA connector bottom
|  | SMA connector top |

Finished assembly 1
Finished assembly 2

---

### Phase 6 - Soldering

**1. Prepare the tube end**

Trim the straight end of the tube to the correct length. Use sandpaper to rough the surface and remove the oxide layer. Clean with isopropyl alcohol.

|Copper Tube|Copper Tube Prepared|
|---|---|

**2. Solder copper tube to SMA connector**

Use a good amount of flux, a heat gun and a soldering iron to attach the end of the tube to the sma connector.

<p align="center">
  
</p>

---

## Build Checklist

### Phase 1 - Rod Preparation & Pacifier Placement
- [ ] Verify pacifier fit on the fiberglass rod
- [ ] Clean fiberglass rod with isopropyl alcohol
- [ ] Mark 10 cm from the top of the rod for the first pacifier position
- [ ] Hot-glue first pacifier in place
- [ ] Rotate assembly while glue cools to prevent sagging
- [ ] Add next pacifier with the spacing template and add hot glue to one side
- [ ] Remove template, reinforce with additional hot glue
- [ ] Repeat for all 22 pacifiers down the rod

### Phase 2 - Epoxy Application
- [ ] Mix two-part epoxy resin and draw into syringes
- [ ] Turn rod upside down, apply epoxy to top face of all pacifier junctions
- [ ] Let cure fully
- [ ] Remove all hot glue
- [ ] Apply epoxy to bottom face of all pacifier junctions
- [ ] Let cure fully

### Phase 3 - Winding the Helical Coil
- [ ] Clamp copper tube to winding form using printed clamps and woodworking clamps
- [ ] Wind copper tube into helix along the full length of the tube and secure with clamps
- [ ] Remove coil from winding form

### Phase 4 - Inserting the Coil
- [ ] Insert coil into pacifier assembly with a rotating motion
- [ ] Trim copper tube flush at the last pacifier
- [ ] Bend the end of the tube straight

### Phase 5 - Base Plate & Final Assembly
- [ ] Drill center hole in aluminum plate for the fiberglass rod
- [ ] Drill holes for M6 cone screws around center hole
- [ ] Drill holes for M2.5 SMA connector screws
- [ ] Drill corner holes for guy-wire string attachment
- [ ] Install SMA connector with 4× M2.5×10 screws and M2.5 nuts
- [ ] Pass rod through plate and mount Top Cone with 8× M6×25 screws and M6 nuts
- [ ] Attach Bottom Cone one the M6 screws

### Phase 6 - Soldering
- [ ] Trim the straight end of the tube
- [ ] Squeeze the end with pliers or use a metal saw to cut it to length (WIP to determine which is better)
- [ ] Prepare the surface with sandpaper and isopropyl alcohol
- [ ] Use flux and an additional heat source like a heat gun and a soldering iron to solder the end to the SMA connector

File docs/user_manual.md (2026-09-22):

# ASCENT II Telemetry System User Manual

Please see the [Operation Advices](#operation-advices) before using the system!

- [Repository Usage](#repository-usage)
- [Electronics](#electronics)
    - [EDA Usage](#eda-usage)
    - [Ordering](#ordering)
    - [Assembly](#assembly)
- [Firmware](#firmware)
    - [IDE Usage](#ide-usage)
    - [Libraries Usage](#libraries-usage)
    - [USB-to-UART/UPDI bridge](#usb-to-uartupdi-bridge)
- [Antenna](#antenna)
    - [Assembly](#assembly-1)
    - [Simulations](#simulations)
    - [Measurements](#measurements)
    - [Impedance Matching](#impedance-matching)
- [Operation Advices](#operation-advices)
    - [Powering The System](#powering-the-system)
    - [Serial Communication](#serial-communication)
    - [Radio Module Troubleshooting](#radio-module-troubleshooting)
    - [Antenna Precautions](#antenna-precautions)
    - [Choice of VGA Cable](#choice-of-vga-cable)

---

# Repository usage

The usual process for locally cloning the repository applies:
1. Install [Git](https://git-scm.com/install/)
2. Open the desired destination folder in the terminal
3. Clone the repository: `git clone https://github.com/Spaceflight-Rocketry-Giessen-e-V/Telemetry` 

---

# Electronics

The process is similar for the onboard and ground station systems.

## EDA Usage

### View and edit the schematic or PCB design files

Our electronics hardware is designed using the open source EDA KiCAD. The schematics and PCB design files can be viewed and are editable. The schematics are also included in PDF format.

### Add custom symbols, footprints and 3D models

The KiCAD project comes with included custom symbol and footprint libraries.
Additional symbols and footprints can be added to these libraries:

- Download the desired files. You can find them on Digikey, Traceparts, Snapmagic, or similar sites. They sould be .kicad_sym (symbol), .kicad_mod (footprint), .step (3D model).
- Put the 3D model in the "3D Model" directory in the same directory as the KiCAD project. The symbol and the footprint can remain in the download folder.

Include the footprint and link the 3D model:
- Open the footprint editor and go "File", "Import", "Footprint"
- Choose the footprint from the download folder
- Press "Save" and insert the desired name and choose the "Footprints" library:



- Press "OK"
- Press "E" to open the footprint properties
- Go to the "3D Models" tab (1), click the folder symbol (2), choose the project path (3), and choose the correcht 3d model (4)



- If the 3D model is not positioned correctly, it can be scaled, rotated, or moved
- Press "OK" and then "Save"

Include the symbol and link the footprint:

- Open the symbol editor, click the "Symbols" library, and go "File", "Import", "Symbol"
- Choose the symbol from the download folder
- Press "Save" and insert the desired name and choose the "Symbols" library
- Press "OK"
- Press "E" to open the symbol properties
- Hover over the "Footprint" field and click the library symbol:



- Choose the footprint from the "Footprints" library
- Press "OK" and then "Save"

## Ordering

### Sourcing PCBs
The PCBs can be sourced from any PCB manufacturing service like JLCPCB or PCBWAY. We included the Gerber Production Files in the repository. We recommend ordering a solder paste stencil as well, as it simplifies the soldering process.

### Sourcing components

We source most of our electronics components from Digikey. We included a Bills of Materials where a direct link to Digikey is provided. Most of the components are also available at similar sellers like Mouser. Interactive BOMs are also included to assist in placing the components.

## Assembly

### SMD component assembly

First, the surface mounted components are soldered. We recommend the Chipquik TS391LT lead free, thermally stable, no-clean, low temperature solder paste, which also comes at a reasonable price. 
To apply the solder paste, the PCB should be cleaned with isopropyl alcohol and then be fixated on a table using surplus PCBs and sticky tape as mechanical stop. 



Next, the solder paste stencil is exactly aligned and fixated with tape as well. 



A small amount of solder paste can be applied and spreaded out using a spatula or an old credit card. When completed, the stencil is removed and the components can be placed on the PCB with tweezers, starting with the smallest components.
We recommend using a hot plate like the Uyue 946C to melt the solder, but a hot air station or a reflow oven can also be used.
Bridged pins can be reworked with flux and a small tip on a soldering iron.

### THT component assembly

After the SMD components are soldered, the through hole mounted components can be soldered. by heating the part and the pad before adding the solder and using a bit of flux, good results can be obtained.

### PCB Cleaning

The PCB can be gently cleaned using a soft toothbrush and isopropyl alcohol. The thereby solved flux can be rinsed with isopropyl alcohol. An ultrasonic cleaner with distilled water can also be used and should be followed up by a complete drying process.

---

# Firmware

## IDE Usage

### View and edit the firmware

Our firmware is designed to be used with Visual Studio Code and the PlatformIO extension. The firmware folder of either the ground station or the onboard system can be directly opened in VSCode. 



### Upload the firmware

To upload, the UPDI USB port can be used. The corresponding COM port has to be selected in VSCode in the status bar.

## Libraries Usage

The repository includes two self-developed libraries, namely the [Radiocrafts RC17xxHP-RC232 Library](/libraries/Radiocrafts_RC17xxHP_RC232/) and the [Dynamic Packet Codec Library](/libraries/DynamicPacketCodec/).

The `platformio.ini` configuration files for the groundstation and onboard firmwares are already configured to include the libraries. For the inclusion in other PlatformIO projects:
- Place the library folder in the `lib` folder of the relevant project or
- Include the folder of the library in the `lib_deps` of the `platformio.ini` file or
- Include `sprog-ev/Radiocrafts_RC17xxHP_RC232@^1.0.0` / `sprog-ev/DynamicPacketCodec@^1.0.0` in the `lib_deps` of the `platformio.ini` file or
- Use the PlatformIO Library Tool

## USB-to-UART/UPDI bridge

Our newest PCB design features one CP2102N USB-to-UART bridge each for UPDI programming and UART debugging and data transfer.

### Drivers

To use the onboard USB bridge to program the microcontroller via UPDI and to transfer data via UART, the [CP210x VCP driver](https://www.silabs.com/software-and-tools/usb-to-uart-bridge-vcp-drivers?tab=downloads) has to be installed.

### LED Setting

By default, the LEDs are not configured to turn on during data transfer.

To configure this setting, the computer has to be connected with a USB cable to the desired chip and the [CP210x VCP driver](https://www.silabs.com/software-and-tools/usb-to-uart-bridge-vcp-drivers?tab=downloads) as well as the [Simplicity Studio 5 software](https://www.silabs.com/software-and-tools/simplicity-studio/simplicity-studio-version-5) have to be installed on the computer.
With the Simplicity Studio software, several settings can be changed, as outlined in the [SiLabs AN721 Application Note](https://www.silabs.com/documents/public/application-notes/AN721.pdf).

The following procedure has to be applied:
1) Open Simplicity Studio.
Press *Welcome*.
When opening for the first time, a new project has to be created: Press *Start* next to the connected device and create the project (the project settings should not be changed). 



2) Open the Xpress Configurator by pressing *Open Perspective* in the top right toolbar.
3) Import the current data from the device.
4) Under *Port Configuration GPIO*, change the *Alternate Function* of GPIO2 and GPIO3 to *TX Toggle* and *RX Toggle* respectively.



5) Save the changes and program to the device.

---

# Antenna 

## Assembly

### Helical Assembly

The assembly of the groundstation helical antenna is described in a [separate document](./helical_antenna_assembly_manual.md).

## Simulations
We do our own simulations of our antennas to validate the proposed designs. The basis is the electromagnetic field solver openEMS developed by Thorsten Liebig. His project can be found on his [GitHub](https://github.com/thliebig/openEMS-Project).
This is only a short description of the simulation process, a longer manual will be added in the future.

The simulation has four main parts:

1. Setting up the parameters of the antenna (eg. number of turns, radius, frequency). The number of parameters depend on: Do you intend to use a computer generated geometry from a CAD software or do you ant to set up the geometry with a script.

2. With the parameters from the first step, the geometry of the antenna and of the groundplate is build. This can either be done through the code itself or by importing a 3D-model of the antenna. We opt to use the import of the 3D-model to better incorporate the complex geometry. The material properties have to be set manually.

3. After creating the antenna and setting up all the parameters, it is now time to set up and run the simulation.

4. The last step is to output the calculated data and visualize it. For the visualization we used [Paraview](https://www.paraview.org/), other software or plot libraries can be used as well.

A more detailed guide can be found [here](helical_antenna_simulation_guide.md).

## Measurements

When measuring self-built or bought antennas, vector network analyzers (VNA) like the NanoVNA-H4 or the LiteVNA 64 are necessary tools and can be bought for cheap.

### Calibration

Before each measurement, the VNA has to be calibrated for the desired frequency range, which should be centered around the frequency of interest, in our case 869.5 MHz. For the measurement of the S11 parameter, the calibration procedure is the following:
1. Input the desired frequency range: STIMULUS -> START, STOP
2. Calibrate with the OPEN SMA connector (no pin in the middle): CALIBRATE -> OPEN
3. Calibrate with the SHORT SMA connector (pin in the middle, looks similar compared to OPEN): CALIBRATE -> SHORT
4. Calibrate with the LOAD SMA connector (pin in the middle, looks different compared to OPEN): CALIBRATE -> LOAD
The calibration data can be saved and used again.

The calibration should always be performed in the exact same way the antenna is tested afterwards. If a cable is going to be used between the VNA and the antenna, the same cable has to be used between the VNA and the OPEN/SHORT/LOAD connectors during calibration.

As an alternative, the length of the cable can also be accounted for in the VNAs software.

### Measurements

There is a range of measurements, which can be done with a VNA. [This article](https://www.antenna-theory.com/measurements/antenna.php) lists the many options.

The most interesting and most feasible measurement is an impedance measurement over a frequency range. An impedance missmatch causes power losses and should be compensated via impedance matching.
Here is a list of videos explaining [S-parameters](https://youtu.be/-Pi0UbErHTY?si=Z9UQJC-R-1Vzc-xW), [the Smith chart](https://youtu.be/TsXd6GktlYQ?si=DfGhaZ3w0biYOcfI) and the application of a VNA ([Video 1](https://youtu.be/rbXq0ZwjETo?si=DdEQ7rzXj86T0cxC) and [Video 2](https://youtu.be/91ZRTFZ40rw?si=-yBII5ZVjXriQ2fS)). [This video](https://youtu.be/l2c46uA50zg?si=s27nZCh-ScBlFWUF) also includes the comparison to a simple simulation software (4NEC2).

The measurement of the radiation pattern or the gain of an antenna is more sophisticated and introduces more errors, but can be done as well.

## Impedance Matching

Our current design includes a L-matching network to tune the antennas impedance to 50 Ohms. When no impedance matching is used, the ZS1 component should be a 0 Ohm resistor and the ZP1 component should be left open

There are many articles and videos explaining the impedance matching concept. [This video](https://youtu.be/OkPVlv4wVeY?si=Ta4NVOyTLGxH_oTO) and [this video](https://youtu.be/IgeRHDI-ukc?si=xvtN1C7xtP1WACcb) explain the matching network and matching technique used in our design, while [this article](https://www.electronicdesign.com/technologies/analog/whitepaper/21133206/back-to-basics-impedance-matchi) offers a general overview over the topic.

---

# Operation Advices

## Powering The System

For the system to be operational, both the 3.3 V and the 5 V lines have to be connected. Any of the respective positions on the pin sockets can be used. To allow the full output power with a safe margin, the power supply should be able to provide 1 A at 5 V and 0.5 A at 3.3 V.

Note: When using an external power supply, the 3.3 V lines of UPDI programmers or UART to USB adapters should never be connected.

## Serial Communication

For the serial communication with the system, an UART to USB adapter has to be used. When using the (planned) integrated USB circuit or an USB adapter based on the CP2102N, the [CP210x VCP driver](https://www.silabs.com/software-and-tools/usb-to-uart-bridge-vcp-drivers?tab=downloads) has to be installed.

We recommend using a dedicated serial monitor like the excellent project [Coolterm](https://freeware.the-meiers.org/), for which we included our [settings file](../groundstation/Coolterm_SerialMonitor_Settings.CoolTermSettings). The settings can be opened via "File" -> "Open".

## Radio Module Troubleshooting

Sometimes the radio modules might seem bricked or malfunctioning. In this case, we advise to reset the internal memory by using: 
```cpp
rc17xx.memoryReset();
```
Sometimes, the radio module boots in the configuration mode, in this case the mode should be exited first:
```cpp
rc17xx.send('X');
delay(100);
rc17xx.memoryReset();
```

## Antenna Precautions

The system should never be operational without a connected antenna, as otherwise the high output power can permanently damage the radio module.

If testing the radio communication between the onboard system and the ground station system, a distance of at least 1.5 m should always be established.

## Choice of VGA Cable

Standard VGA cables are not applicable here, since the pinout is configured that pins that either carry a digital signal or are connected to ground are internally connected. This renders the standart VGA cable useless. Use VGA breakout cables, a DIY cabel or search online for a cable with 15 individual connections.

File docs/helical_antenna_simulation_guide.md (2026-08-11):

# Antenna Simulation with openEMS

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

Check out the [repository](https://github.com/thliebig/openEMS-Project) to get a better look at what it can do, and leave a star for the repository to support the amazing work of Thorsten Liebig and the other contributors.

## To run the Simulation

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

### Octave
#### Unix-likes
Go to the [Octave Wiki](https://wiki.octave.org/Category:Installation)

For example Arch:
```
pacman -S octave
```
#### Windows
On the [download page](https://octave.org/download) get the version that fits your system

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

## The antenna
The antenna is an axial-mode RHCP *(right-hand circular polarisation)* helix antenna for a frequency of $f=869.525\,\mathrm{MHz}$. Find the specifications in the [Design Overview](/docs/design_overview.md).

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

In our code this is handled by these 4 use cases:

```matlab
disp('  [1] Full run       -- build, simulate, post-process');
disp(sprintf('  [2] Post-proc only -- re-use existing %s/ results', aux_dir_name));
disp('  [3] Geometry check -- open AppCSXCAD, then stop');
disp('  [4] Preview + run  -- geometry check first, then simulate');
```
A *Full run* has to be done to generate the data [2] re-uses. [3] and [4] build the geometry
themselves and need nothing beforehand.

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

```matlab
[script_dir, script_name] = fileparts(mfilename('fullpath'));
aux_dir_name = 'Simulation_auxiliary_files';
Sim_Path = fullfile(script_dir, aux_dir_name);
Sim_CSX  = [script_name '.xml'];
```

So `Helical_Antenna.m` writes its geometry to `Simulation_auxiliary_files/Helical_Antenna.xml`, and
everything the run produces, field dumps, port data, figures, the VTK, lands in that same
`Simulation_auxiliary_files/` folder next to the script. Rename or copy the script and the XML
follows the new name, which keeps two variants from overwriting each other's geometry.
### Frequency and excitation
```matlab
f0 = 869.525e6;
fc = 100e6;
FDTD = InitFDTD('NrTS', 1e6, 'EndCriteria', 1e-5);
FDTD = SetGaussExcite(FDTD, f0, fc);
```

The antenna is not simulated at one frequency. The excitation is a short pulse, which gives us the whole band in a single run, like a VNA sweep.

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

<div align="center">

| Parameter | Value |
|:---:|:---:|
| `fc` | 100 MHz |
| Excited band | 769.5 … 969.5 MHz |

</div>

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

### Boundary conditions
```matlab
BC = {'PML_8' 'PML_8' 'PML_8' 'PML_8' 'PML_8' 'PML_8'};
FDTD = SetBoundaryCond(FDTD, BC);
```

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

```matlab
air_gap = 0.75 * lambda0;   % 258.6 mm = 79.6 mm PML + 179 mm real air (0.52 lambda)
```

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

```matlab
mesh.x = SmoothMeshLines([-Helix.radius 0 Helix.radius], Helix.mesh_res);  % 1.5 mm
mesh_x_tmp = [mesh.x, -gnd_size/2, gnd_size/2, -sim_r, sim_r];
mesh.x = AutoSmoothMeshLines(mesh_x_tmp, max_res, grade);                  % out to 10 mm
```

`SmoothMeshLines` puts 1.5 mm lines across the helix, `AutoSmoothMeshLines` grows them out to
`max_res` with no cell more than `grade = 1.2`× its neighbour. `max_res` is λ/30 at the *highest*
excited frequency, not at `f0`, but at `c0/(f0+fc)/30` = 309 mm / 30 → 10 mm. The ramp has to be
gradual and not an abrupt size jump which reflects waves off the grid itself.

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

### Geometry: helix, ground plane, feed
The parametric equation of a coil, sampled into points and given a thickness:

```matlab
t = linspace(0, 2*pi*Helix.turns, pts*ceil(Helix.turns));
coil_x = Helix.radius * cos(t);
coil_y = Helix.radius * sin(t);
coil_z = (t/(2*pi)) * Helix.pitch + feed.height;   % rises one pitch per turn
CSX = AddWire(CSX, 'helix', 0, p, Helix.wire_rad);
```

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

*The ground plane*, a 64-sided polygon standing in for a 400 mm disc:

```matlab
theta_gnd = (0:num_gnd_pts-1) * 2*pi/num_gnd_pts;   % NOT linspace(0, 2*pi, N)
```

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

*The feed*, a lumped port up the 15 mm gap between ground plane and helix:

```matlab
[CSX, port] = AddLumpedPort(CSX, 5, 1, feed.R, start, stop, [0 0 1], true);
```

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

### NF2FF box
```matlab
start_nf = [mesh.x(11) mesh.y(11) mesh.z(11)];
stop_nf  = [mesh.x(end-10) mesh.y(end-10) mesh.z(end-10)];
```

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

## Running it
The menu at the top of the script sets three flags: `run_fdtd`, `show_geometry`, `do_postproc`.

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

```matlab
RunOpenEMS(Sim_Path, Sim_CSX, ['--engine=multithreaded' thread_opt ' --dump-statistics']);
```

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

Asking for more threads than you have only warns; openEMS clamps to `hardware_concurrency()` itself.

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

All three result panels in one figure

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

All of them inside `Simulation/Simulation_auxiliary_files/`:

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

```matlab
Zin = port.uf.tot ./ port.if.tot;
s11      = (Zin - Z0)     ./ (Zin + Z0);      % Z0 = 50, the real coax
s11_feed = (Zin - feed.R) ./ (Zin + feed.R);  % 140, the port reference
```

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

Real and imaginary part of the input impedance over the excited band

S11 referenced to 50 ohm and to 140 ohm

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

| | Simulated | Kraus |
|:---:|:---:|:---:|
| $D_\mathrm{max}$ | 12.8 dBi | 13.2 dBi |
| HPBW | 37° | 44° |

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

The bottom panel splits the pattern into the two circular polarizations:

```matlab
directivity_CPRH = abs(nf2ff.E_cprh{1}).^2 ./ max(nf2ff.E_norm{1}(:)).^2 * nf2ff.Dmax;
```

| At boresight | |
|:---:|:---:|
| RHCP | 12.7 dBi |
| LHCP | −3.3 dBi |
| Axial ratio | 2.8 dB |

Directivity vs theta, total and split into RHCP and LHCP

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

```matlab
ML_50   = 10*log10(1 - abs(s11(i0))^2);
ML_feed = 10*log10(1 - abs(s11_feed(i0))^2);
```

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

```matlab
DumpFF2VTK([Sim_Path '/3D_Pattern.vtk'], directivity, thetaRange, phiRange, 'scale', 1e-3);
```

Colour by `gain`, no Calculator needed. Peak equals $D_\mathrm{max}$.

## Limitations and sanity checks
What the model leaves out:

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

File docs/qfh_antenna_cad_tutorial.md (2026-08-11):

# QFH Antenna CAD Tutorial

### Using Autodesk Fusion

- [Copper Wire](#copper-wire)
    - [Step 1: Create Two Triangular Coils](#step-1-create-two-triangular-coils)
    - [Step 2: Turn The Coils Into A 3D Sketch](#step-2-turn-the-coils-into-a-3d-sketch)
    - [Step 3: Add Horizontal Sections](#step-3-add-horizontal-sections)
    - [Step 4: Add Corner Bending](#step-4-add-corner-bending)
    - [Step 5: Create The Copper Wire](#step-5-create-the-copper-wire)
    - [Step 6: Clean Up The Project](#step-6-clean-up-the-project)
- [Winding Help](#winding-help)
    - [Step 1: Create Cylindrical Bodies](#step-1-create-cylindrical-bodies)
    - [Step 2: Create Wire Grooves](#step-2-create-wire-grooves)
    - [Step 3: Create Corner Grooves](#step-3-create-corner-grooves)

---

# Copper Wire

## Step 1: Create Two Triangular Coils

Use `Create` &rarr; `Coil` with the shown settings and adjust the diameter and height if needed. Be aware of the correct rotation for RHCP and LHCP antennas. For RHCP, the rotation should be counter-clockwise (as shown in the screenshot).

<p align="center"><image src='images/qfh_antenna_cad_tutorial/copper wire/1.png' width = 500></p>

Use `Move/Copy` to create a copy of the coil. Turn it by 180° around the origin.

<p align="center"><image src='images/qfh_antenna_cad_tutorial/copper wire/2.png' width = 500></p>

## Step 2: Turn The Coils Into A 3D Sketch

Use `Create` &rarr; `Sketch` to create a sketch in die horizontal plane. Activate the `Sketch Palette` &rarr; `3D Sketch` Checkbox.

<p align="center"><image src='images/qfh_antenna_cad_tutorial/copper wire/3.png' width = 500></p>

Use `Create` &rarr; `Project/Include` &rarr; `Include 3D Geometry`. Click the outer profile of each of the coils.

<p align="center"><image src='images/qfh_antenna_cad_tutorial/copper wire/4.png' width = 500></p>

<p align="center"><image src='images/qfh_antenna_cad_tutorial/copper wire/5.png' width = 500></p>

Click on one of the projection, click on the small symbol and press delete to delete the projection and create a spline. Repeat for the other projection.

<p align="center"><image src='images/qfh_antenna_cad_tutorial/copper wire/6.png' width = 500></p>

The result should look like this:

<p align="center"><image src='images/qfh_antenna_cad_tutorial/copper wire/7.png' width = 500></p>

## Step 3: Add Horizontal Sections

Pick one end of one spline. Use `Create` &rarr; `Line` to draw a line from the end point towards the origin. The length should equal your desired bending radius. 

<p align="center"><image src='images/qfh_antenna_cad_tutorial/copper wire/8.png' width = 500></p>

Repeat for all four spline ends and connect the two top sections and two bottom sections. The result should look like this:

<p align="center"><image src='images/qfh_antenna_cad_tutorial/copper wire/9.png' width = 500></p>

## Step 4: Add Corner Bending

Pick one end of one spline. Use `Create` &rarr; `Line` to draw a line.

<p align="center"><image src='images/qfh_antenna_cad_tutorial/copper wire/10.png' width = 500></p>

Drag the line along the spline until the length reaches the bending radius. It is important that the line snaps to the spline, you might zoom in a bin. In the screenshot it looks off, but the look of the cross is important. 

<p align="center"><image src='images/qfh_antenna_cad_tutorial/copper wire/11.png' width = 500></p>

Use `Modify` &rarr; `Trim` to trim the spline section between the two intersections with the drawn line.

<p align="center"><image src='images/qfh_antenna_cad_tutorial/copper wire/12.png' width = 500></p>

Use `Modify` &rarr; `Blend Curve` to connect the remaining spline to the horizontal line.

<p align="center"><image src='images/qfh_antenna_cad_tutorial/copper wire/13.png' width = 500></p>

Repeat for all four corners.

<p align="center"><image src='images/qfh_antenna_cad_tutorial/copper wire/14.png' width = 500></p>

## Step 5: Create The Copper Wire

Use `Create` &rarr; `Pipe` to create the copper wire along the profile and choose the wire diameter.

<p align="center"><image src='images/qfh_antenna_cad_tutorial/copper wire/15.png' width = 500></p>

## Step 6: Clean Up The Project

Use `Remove` (not `Delete`!) to remove the two triangular spirals.

<p align="center"><image src='images/qfh_antenna_cad_tutorial/copper wire/16.png' width = 500></p>

---

# Winding Help

## Step 1: Create Cylindrical Bodies

Use `Create` &rarr; `Sketch` to create a sketch in the horizontal plane and draw a circle with the diameter of the QFH antenna.

<p align="center"><image src='images/qfh_antenna_cad_tutorial/winding help/1.png' width = 500></p>

Use `Create` &rarr; `Extrude` to extrude a cylinder with a positive offset of half the wire thickness to the top of the QFH.

<p align="center"><image src='images/qfh_antenna_cad_tutorial/winding help/2.png' width = 500></p>

Use `Create` &rarr; `Extrude` to extrude a cylinder with a positive offset of half the wire thickness downwards.

<p align="center"><image src='images/qfh_antenna_cad_tutorial/winding help/3.png' width = 500></p>

## Step 2: Create Wire Grooves

Use `Modify` &rarr; `Combine` to combine the wire with the big cylinder. Use the `Cut` operation and `Keep Tools` option.

<p align="center"><image src='images/qfh_antenna_cad_tutorial/winding help/4.png' width = 500></p>

Use `Modify` &rarr; `Combine` to combine the wire with the small cylinder. Use the `Cut` operation and `Keep Tools` option.

<p align="center"><image src='images/qfh_antenna_cad_tutorial/winding help/5.png' width = 500></p>

Use `Create` &rarr; `Sketch` to create a sketch in the vertical plane. Use `Draw` &rarr; `Circle` to draw a circle with the diameter of the wire and the center in the origin. Use `Draw` &rarr; `Circle` to draw a flat top and sides. Extrude the profile symmetrically and use the `Cut` operation to cut a groove into the lower cylinder.

<p align="center"><image src='images/qfh_antenna_cad_tutorial/winding help/6.png' width = 500></p>

## Step 3: Create Corner Grooves

Pick one of the corners. Use `Construct` &rarr; `Plane Through Three Points` to construct a plane through the three corner points of the wire sketch (two intersection points of the blend curve and the outermost corner point).

<p align="center"><image src='images/qfh_antenna_cad_tutorial/winding help/7.png' width = 500></p>

Use `Create` &rarr; `Sketch` to create a sketch in the new plane. Use `Draw` &rarr; `Line` to draw a line between the two intersection points of the blend curve. Use `Draw` &rarr; `Rectangle` to draw a rectangle between the outermost corner point and the intersection of the blend curve with the QFH spline.

<p align="center"><image src='images/qfh_antenna_cad_tutorial/winding help/8.png' width = 500></p>

Project the small horizontal segment and the blend curve into the sketch.

<p align="center"><image src='images/qfh_antenna_cad_tutorial/winding help/9.png' width = 500></p>

Use `Create` &rarr; `Extrude` to extrude the innermost round profile symmetrically with thickness of half the wire diameter.

<p align="center"><image src='images/qfh_antenna_cad_tutorial/winding help/10.png' width = 500></p>

Use `Construct` &rarr; `Tangent Plane` to construct a plane tangent to the cylinder side.

<p align="center"><image src='images/qfh_antenna_cad_tutorial/winding help/11.png' width = 500></p>

Use `Create` &rarr; `Sketch` to create a sketch on the new plane. Project the outward facing side of the round extrusion onto the sketch.

<p align="center"><image src='images/qfh_antenna_cad_tutorial/winding help/12.png' width = 500></p>

Extrude this profile with `To Object` Extend Type and `Cut` Operation and select the round profile as the end.

<p align="center"><image src='images/qfh_antenna_cad_tutorial/winding help/13.png' width = 500></p>

`Remove` the round extrusion.

Use `Create` &rarr; `Extrude` to extrude the rest of the three point plane sketch towards the sharp corner, use the `Cut` option but only cut the big cylinder.

<p align="center"><image src='images/qfh_antenna_cad_tutorial/winding help/14.png' width = 500></p>

The result should look like this.

<p align="center"><image src='images/qfh_antenna_cad_tutorial/winding help/15.png' width = 500></p>

Repeat for all four corners.

<p align="center"><image src='images/qfh_antenna_cad_tutorial/winding help/16.png' width = 500></p>

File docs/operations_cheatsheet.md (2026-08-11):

# Operations cheatsheet / operations manual

- [Radio Command Reference](#radio-command-reference)
- [Status Events Reference](#status-events-reference)
- [Groundstation LED Reference](#groundstation-led-reference)

---

## Radio Command Reference

The command input can be in either lower or upper case letters.
Upper case letters will be converted to lower case letters before transmission.
|Char|Function|Subsystem|
|:---:|---|---|
|`a`|Arming|All|
|`b`|Dearming|All|
|`f`|Flight Mode Activation|Telemetry|
|`g`|Flight Mode Deactivation|Telemetry|
|`h`|Change Pressure Sensor|Sensorics|
|`i`|Change Acceleration Sensor|Sensorics|
|`j`|Change GNSS Receiver|Sensorics|
|`l`|Low Power Mode Activation|All|
|`m`|Low Power Mode Dectivation|All|
|`p`|Ping (Request Both Data Packets)|Telemetry|
|`q`|Drogue Parachute Ejection|Flight Control|
|`r`|Main Parachute Ejection|Flight Control|
|`s`|Decoupler Decoupling|Flight Control|
|`t`|Change Main Parachute Ejection Height|Flight Control|
|`v`|Delete Flash Content|Sensorics|
|`w`|Enter Flash Write Mode|Sensorics|

## Status Events Reference

> Status events are not yet defined.

|Event|Description||Event|Description|
|:---:|---|---|:---:|---|
|`0`|||`16`||
|`1`|||`17`||
|`2`|||`18`||
|`3`|||`19`||
|`4`|||`20`||
|`5`|||`21`||
|`6`|||`22`||
|`7`|||`23`||
|`8`|||`24`||
|`9`|||`25`||
|`10`|||`26`||
|`11`|||`27`||
|`12`|||`28`||
|`13`|||`29`||
|`14`|||`30`||
|`15`|||`31`||

## Groundstation LED Reference

|LED|Indication|
|:---:|---|
|`D11`|+3V3|
|`D12`|+5V|
|`D1`|General Status LED|
|`D2`|Radio module 1 initialised|
|`D3`|Radio module 2 initialised|
|`D4`|Red: Setup begin <br> Blue: Setup radio modules <br> Green: Setup complete|
|`D27` - `D34`|RSSI Indication <br> All LEDs lit: RSSI > -40 dBm <br> No LED lit: RSSI < -110 dBm <br> One LED = $\pm$10 dBm|

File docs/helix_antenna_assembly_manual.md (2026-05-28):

# Helix Antenna Build Manual

This document describes how we built our helical groundstation antenna for receiving telemetry from our rockets. 

---

## Table of Contents

- [Overview](#overview)
- [Bill of Materials](#bill-of-materials)
  - [3D-Printed Design Files](#3d-printed-design-files)
- [Build Process](#build-process)
  - [Phase 1 — Rod Preparation \& Pacifier Placement](#phase-1--rod-preparation--pacifier-placement)
  - [Phase 2 — Epoxy Application](#phase-2--epoxy-application)
  - [Phase 3 — Winding the Helix Coil](#phase-3--winding-the-helix-coil)
  - [Phase 4 — Inserting the Coil](#phase-4--inserting-the-coil)
  - [Phase 5 — Base Plate \& Final Assembly](#phase-5--base-plate--final-assembly)
  - [Phase 6 — Soldering](#phase-6--soldering)
- [Build Checklist](#build-checklist)

---

## Overview

The mechanical design of the helix antenna is explained in the [design overview](design_overview.md#mechanical-design).

|Side View | Base Detail|
|---|---|

---

## Bill of Materials

|Item|Specification|Est. Cost (€)|
|---|---|:---:|
|Fiberglass Rod|2 m length, 30 mm diameter|60|
|Aluminum Plate|70 × 70 cm, 2 mm thickness|35|
|Copper Tube|15 m length, 6 mm diameter, hollow|60|
|[SMA Connector](https://www.digikey.de/de/products/detail/te-connectivity-linx/CONSMA016-15-G/11624645)|TE Connectivity CONSMA016-15-G|7|
|[Pacifier](../groundstation/antenna/Auxiliary%20Design%20Files/Pacifier.stl)|22× (3D printed)|-|
|[Pacifier Fixture](../groundstation/antenna/Auxiliary%20Design%20Files/Pacifier%20Fixture.stl)|1× (3D printed)|-|
|[Cone Top](../groundstation/antenna/Auxiliary%20Design%20Files/Cone%20Top.stl)|1× (3D printed)|-|
|[Cone Bottom](../groundstation/antenna/Auxiliary%20Design%20Files/Cone%20Bottom.stl)|1× (3D printed)|-|
|[Rope Fixture](../groundstation/antenna/Auxiliary%20Design%20Files/Rope%20Fixture.stl)|1× (3D printed)|-|
|[Winding Clamp](../groundstation/antenna/Auxiliary%20Design%20Files/Winding%20Clamp.stl)|1× (3D printed)|-|
|[Winding Help](../groundstation/antenna/Auxiliary%20Design%20Files/Winding%20Help.stl)|1× (3D printed)|-|
|M8 × 30 Screws|8×|-|
|M8 Nuts|8×|-|
|M2.5 × 10 Screws|4×|-|
|M2.5 Nuts|4×|-|
|Epoxy Resin + Hardener|with syringes and mixing equipment|10|
|Hot Glue Sticks|for temporary fixturing|-|
|Isopropyl Alcohol|for surface cleaning|-|
|String / Guy Wire| for structural bracing, non metallic|5|
|**Total (excl. 3D printing)**||**177**|

### 3D-Printed Design Files

All 3D models are available in the [`groundstation/antenna/`](../groundstation/antenna/) subfolder:

- Original Design Files: Native `.f3z` Autodesk Fusion files
- Auxiliary Design Files: Parts exported as `.stl` and `.step`

---

## Build Process

### Phase 1 — Rod Preparation & Pacifier Placement

**1. The pacifiers**

The "pacifiers" are 3D-printed ring fixtures that hold the copper coil at the correct spacing and angle along the fiberglass rod. They are the most integral part of the assembly since they decide the final geometry.

|Pacifier part|Template placement|
|---|---|
|[Pacifier](../groundstation/antenna/Auxiliary%20Design%20Files/Pacifier.stl)|[Pacifier Spacer](../groundstation/antenna/Auxiliary%20Design%20Files/Pacifier%20Fixture.stl)|

<p align="center">
  Pacifier and template
</p>

**2. Prepare the rod**

Lay the fiberglass rod on your work surface and clean it thoroughly with isopropyl alcohol.

|Rod|Cleaned rod|
|---|---|

**3. Set the first pacifier**

Place the first pacifier 10 cm from the top of the rod. You will work your way down from the top.

<p align="center">
  First pacifier placed
</p>

**4. Attach with hot glue**

Attach the first pacifier with hot glue. Using the 3D-printed pacifier spacer, position and hot-glue each pacifier. Apply a small amount first, just enough for initial stability. Wait for the glue to partially cure, remove the template, then add more hot glue around the perimeter of the pacifier. Rotate the entire assembly slowly for a few seconds while the glue cools to prevent it from sagging or setting off-axis.

Cooling can be accelerated with compressed air or a fan. Our compressor had issues on build day, so we had to cool it the old-fashioned way — by blowing on a long rod for several hours. Highly recommended workout for the lungs.

Repeat for all pacifiers down the rod.

|Hot glued|Template set|
|---|---|
| Template set 2|Next pacifier glued|

The result should look like this:

|Final rod assembly 2|Final rod assembly|
|---|---|

Due to 3D printing tolerances, the template may introduce a small angular offset between pacifiers. This is minor and acceptable.

---

### Phase 2 — Epoxy Application

Always wear a respirator mask and eye protection and open the windows when working with epoxy resin. A helmet is advised for the looks.

<p align="center">
  Wear a mask
</p>
**1. Mount for curing**

Attach one spare pacifier to the topmost part of the rod and hang the assembly from a shelf so the epoxy can be applied and cure fully upright, without placing stress on any of the pacifiers.

|Shelf attachment|Shelf attachment 2|
|---|---|

**2. Mix and draw up epoxy**

Mix the two-part epoxy resin according to the manufacturer's instructions. Draw it into syringes with large blunt-tip needles for controlled application.

|Epoxy resin|Drawing epoxy into syringe|
|---|---|

**3. First application — top side of rings**

Turn the rod upside down. Apply epoxy to the top face of each pacifier-to-rod junction. The bottom face is still covered by hot glue at this point, so leave it.

|Epoxy application|Epoxy application 2|
|---|---|
|Epoxy application 3|Pacifier done|

The epoxy may wick into small gaps between the pacifier and the rod which should increase the bonding strength. However, drips are undesired and hould be wiped with acetone.

**4. Second application — bottom side of rings**

Remove the rod from the shelf fixture, turn it around and reinsert it in the fixture. 

Remove the hot glue, then apply epoxy to the previously covered bottom faces of each pacifier.

| Round two | Round two 2 |
|---|---|

Allow to cure fully before proceeding.

---

### Phase 3 — Winding the Helix Coil

**1. The winding template**

Use the 3D-printed winding help form to shape the copper tube into the correct helix diameter. Printed winding clamps hold the tube against the form, secured with woodworking clamps.

|Full template|Template attachment|
|---|---|
|[Winding Help](../groundstation/antenna/Auxiliary%20Design%20Files/Winding%20Help.stl)|[Winding Clamp](../groundstation/antenna/Auxiliary%20Design%20Files/Winding%20Clamp.stl)|

**2. Wind the coil**

With the tube clamped to the template, rotate it around the mandrel in a continuous helical motion, and secure it after each turn with a clamp. The copper tube should more or less keep its shape.

|Winding 1|Winding 2|
|---|---|
|Winding 3|Winding 4|

The coil may not seem be perfectly straight due to its springy behaviour, but this does not affect function since it will be hold by the pacifiers.

|Finished side|Finished coil top|
|---|---|

<p align="center">
  Finished coil angle
</p>
---

### Phase 4 — Inserting the Coil

**1. Insert the coil into the pacfifiers**

Insert the finished coil into the pacifier assembly on the rod with a smooth rotating motion.

|Inserting coil|Inserting coil 2|
|---|---|

This step is very easy and should take about 5 minutes.

**2. Trim the coil**

Once fully seated, trim the copper tube flush at the last pacifier.

|Finished coil antenna assembly|Cut end|
|---|---|

**3. Bend the end straight**

Bend the end of the tube straight towards the groundplane.

---

### Phase 5 — Base Plate & Final Assembly

**1. Prepare the aluminum ground plane**

Drill a center hole through the aluminum plate sized to pass the fiberglass rod. Around it, drill holes for the cone mounting screws (M8). Add holes for the SMA connector (M2.5). The [included drilling template](../groundstation/antenna/drilling_template.pdf) can be used: print it and stick it on the plate with adhesive.

This is also a good time to drill the corner holes for the guy-wire string attachment, while the plate is already on the drill press.

|Cones|Drilled plate|
|---|---|

**2. Assemble the cones and connector**

Install the SMA connector using the M2.5 screws. Pass the rod through the plate. Mount the [Top Cone](../groundstation/antenna/Auxiliary%20Design%20Files/Cone%20Top.stl) from above and bolt it down with the M8 screws. Finally, attach the [Bottom Cone](../groundstation/antenna/Auxiliary%20Design%20Files/Cone%20Bottom.stl) from below, by removing the nuts from the Top Cone, and using them to bolt the Bottom Cone to the Top Cone

|Top cone screwed on (top view)|Top cone screwed on (bottom view)|
|---|---|
|SMA connector bottom|SMA connector top|

Finished assembly

**3. Attach the rope fixture and guy wires**

Glue the [Rope Fixture](https://github.com/Spaceflight-Rocketry-Giessen-e-V/Telemetry/blob/main/groundstation/antenna/Auxiliary%20Design%20Files/Rope%20Fixture.stl) with epoxy resin to the very top of the rod. After curing, run strings from each corner of the aluminum plate up to the fixture.

<p align="center">
  Assembly with strings
</p>
If adhesion between the pacifiers and the rod seems insufficient, it is possible to design and 3D-print connector bridges between adjacent pacifiers for added rigidity. This should be integrated during Phase 2. We opted against it due to weight and material concerns, but the option exists.

---

### Phase 6 — Soldering

**1. Prepare the tube end**

Trim the straight end of the tube to the correct length. Use sandpaper to rough the surface and remove the oxide layer. Clean with isopropyl alcohol.

|Copper Tube|Copper Tube Prepared|
|---|---|

**2. Solder copper tube to SMA connector**

Use a good amount of flux, a heat gun and a soldering iron to attach the end of the tube to the sma connector.

<p align="center">
  
</p>

---

## Build Checklist

### Phase 1 — Rod Preparation & Pacifier Placement
- [ ] Verify pacifier fit on the fiberglass rod
- [ ] Clean fiberglass rod with isopropyl alcohol
- [ ] Mark 10 cm from the top of the rod for the first pacifier position
- [ ] Hot-glue first pacifier in place
- [ ] Rotate assembly while glue cools to prevent sagging
- [ ] Add next pacifier with the spacing template and add hot glue to one side
- [ ] Remove template, reinforce with additional hot glue
- [ ] Repeat for all 22 pacifiers down the rod

### Phase 2 — Epoxy Application
- [ ] Mix two-part epoxy resin and draw into syringes
- [ ] Turn rod upside down, apply epoxy to top face of all pacifier junctions
- [ ] Let cure fully
- [ ] Remove all hot glue
- [ ] Apply epoxy to bottom face of all pacifier junctions
- [ ] Let cure fully

### Phase 3 — Winding the Helix Coil
- [ ] Clamp copper tube to winding form using printed clamps and woodworking clamps
- [ ] Wind copper tube into helix along the full length of the tube and secure with clamps
- [ ] Remove coil from winding form

### Phase 4 — Inserting the Coil
- [ ] Insert coil into pacifier assembly with a rotating motion
- [ ] Trim copper tube flush at the last pacifier
- [ ] Bend the end of the tube straight

### Phase 5 — Base Plate & Final Assembly
- [ ] Drill center hole in aluminum plate for the fiberglass rod
- [ ] Drill holes for M8 cone screws around center hole
- [ ] Drill holes for M2.5 SMA connector screws
- [ ] Drill corner holes for guy-wire string attachment
- [ ] Install SMA connector with 4× M2.5×10 screws and M2.5 nuts
- [ ] Pass rod through plate and mount Top Cone with 8× M8×30 screws and M8 nuts
- [ ] Attach Bottom Cone one the M8 screws
- [ ] Glue Rope Fixture to top of rod with epoxy resin, let cure fully
- [ ] Run string from each corner of aluminum plate up to rope fixture

### Phase 6 — Soldering
- [ ] Trim the straight end of the tube
- [ ] Squeeze the end with pliers
- [ ] Prepare the surface with sandpaper and isopropyl alcohol
- [ ] Use flux and an additional heat source like a heat gun and a soldering iron to solder the end to the SMA connector

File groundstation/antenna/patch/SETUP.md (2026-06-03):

# Setup — RHCP Patch Antenna Optimizer

This project drives the [openEMS](https://www.openems.de/) FDTD solver through its
Python bindings. Those bindings (`CSXCAD`, `openEMS`) are **not on PyPI or conda**,
so `pip install -r requirements.txt` alone is **not** enough — `python run.py` will
otherwise fail with `ModuleNotFoundError: No module named 'CSXCAD'`.

There are three things that must all be in place; `run.py` checks for them on launch
and prints an actionable message if any is missing.

| # | Requirement | Why |
|---|---|-----|
| 1 | A native **openEMS** install (`CSXCAD.dll`, `openEMS.dll`, VTK/Qt5/boost DLLs) | The Python wheels are thin Cython wrappers; the actual solver lives in these DLLs. |
| 2 | **`OPENEMS_INSTALL_PATH`** pointing at that folder | The bindings call `os.add_dll_directory(os.environ['OPENEMS_INSTALL_PATH'])` at import to find the DLLs. `run.py` auto-detects `C:\Program Files\openEMS` if the variable is unset. |
| 3 | The `csxcad` + `openems` **wheels matching your Python minor** (`cp314` ⇄ Python 3.14) | A compiled-extension wheel only loads on the exact CPython minor it was built for. |

## Prerequisites

- **Python 3.14** (see [`.python-version`](.python-version)). The bundled bindings are
  `cp314` wheels; a 3.12/3.13 venv will reject them with *"not a supported wheel on
  this platform"*.
- A native **openEMS** install. The bindings are version-locked to it.

## Install (Windows)

```powershell
# 1. Native openEMS — install it so CSXCAD.dll / openEMS.dll exist on disk,
#    e.g. at C:\Program Files\openEMS, and (optionally) set the env var:
#       setx OPENEMS_INSTALL_PATH "C:\Program Files\openEMS"
#    run.py auto-detects C:\Program Files\openEMS, so the env var is optional
#    only when openEMS lives there.

# 2. Create the venv with Python 3.14 and install the PyPI deps:
py -3.14 -m venv .venv
.\.venv\Scripts\Activate.ps1
python -m pip install -r requirements.txt

# 3. Install the openEMS bindings from the wheels bundled in your openEMS
#    install (adjust the path; the cp tag must match your Python — cp314 here):
python -m pip install `
    "C:\Program Files\openEMS\python\csxcad-*-cp314-*.whl" `
    "C:\Program Files\openEMS\python\openems-*-cp314-*.whl"

# 4. Verify and run (run from this folder — run.py uses `import config` / `src.*`):
python -c "import CSXCAD, openEMS; print('bindings OK')"
python run.py
```

## Troubleshooting

| Symptom | Cause | Fix |
|---|---|-----|
| `ModuleNotFoundError: No module named 'CSXCAD'` | Step 3 not done — bindings not in this venv. | Install the wheels (step 3) into the venv you launch with. |
| `ImportError: DLL load failed while importing CSXCAD` | DLLs not found: no native openEMS, or `OPENEMS_INSTALL_PATH` wrong/unset and openEMS isn't at `C:\Program Files\openEMS`. | Install native openEMS (step 1) and set `OPENEMS_INSTALL_PATH` to its folder. |
| `... is not a supported wheel on this platform` | Python minor ≠ the wheel's `cp` tag (e.g. `cp310` wheel into a 3.14 venv). | Use a Python whose version matches the wheels, or get wheels built for your Python. |

## A note on reproducibility

The bindings are **not redistributable from any public index**, and the openEMS build
currently in use here is a **local/custom build** (its `cp313`/`cp314` wheels were built
in Oct 2025; the only public release, `v0.0.36`, is from Oct 2023 and ships `cp310`
wheels). That means a teammate **cannot** reproduce this exact setup from an upstream
download — they need the same openEMS build and matching wheels.

How to distribute that build to teammates (self-host your wheels + native runtime, or
standardize on a Python version that has an official openEMS release) is an **open
decision** — this document and `run.py`'s preflight check are the interim safety net so
launches fail with clear guidance rather than a stack trace.

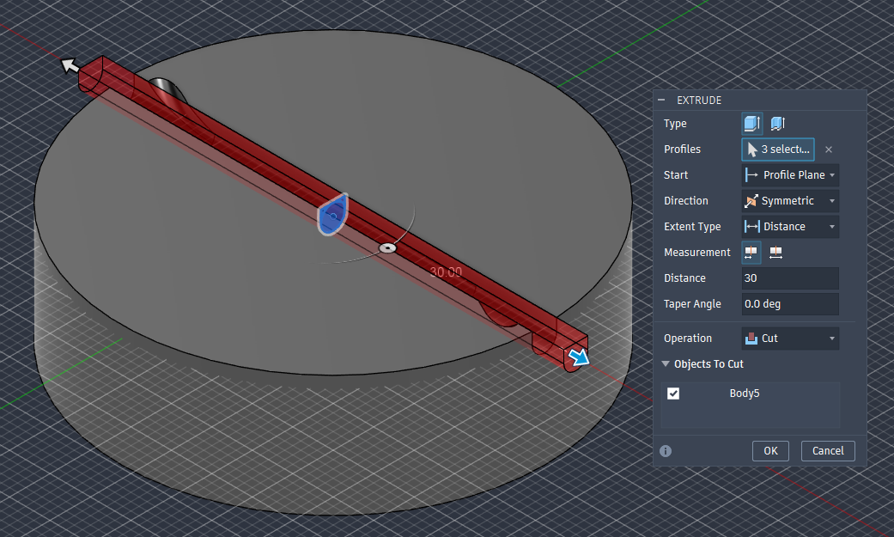
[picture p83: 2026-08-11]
docs/images/qfh_antenna_cad_tutorial/winding help/6.png

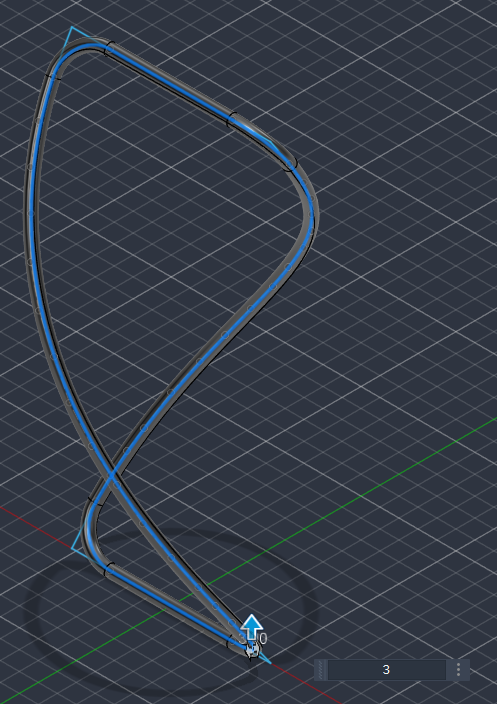
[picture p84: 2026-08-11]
docs/images/qfh_antenna_cad_tutorial/copper wire/15.png

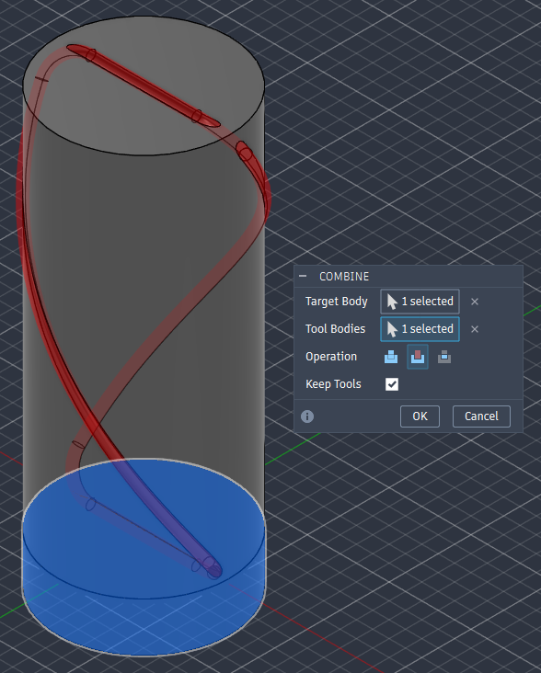
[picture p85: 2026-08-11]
docs/images/qfh_antenna_cad_tutorial/winding help/5.png

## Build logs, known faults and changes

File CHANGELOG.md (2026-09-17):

# Changelog

All notable changes to this project will be documented in this file.

The format is based on [Keep a Changelog](https://keepachangelog.com/en/1.1.0/).

Since our projects include multiple subsytems, which are developed more or less seperately (hardware, firmware, gui software), we decided to NOT use semantic versioning. The major versions of the whole project can be identified by their release date. However, the pcb designs include revision indications.

## [UNRELEASED]:

### Added
- Daughterboard and Motherboard Electronics Casings
- Onboard Electronics Mounting Structure
- 869 MHz Groundstation Patch Antenna
- 869 MHz Groundstation Helical Antenna Simulation Files
- QFH Antenna CAD Tutorial
- Dynamic Packet Codec Library
- Firmware/Libraries Code Reference (GitHub Pages) incl. automatic deployment

### Changed
- Complete firmware rework
- Redefinition of packet structures
- Major helical antenna rework with smaller design
- Replotted figures in the helical antenna design guide

### Removed
- Hard-coded Packet Codec Library

### Fixed
- Several GUI issues

### Deprecated

## 2026-06-02:

### Added
- New purpose-built groundstation electronics (motherboard/daughterboard design)
- Helix antenna for the groundstation
- GUI command transmission
- New GUI windows: commands, connection, settings, time, and acceleration
- run.bat launcher for the GUI and new Arduino simulation sketches (v2, v3, CSV replay)

### Changed
- Onboard electronics redesigned for dual-band operation
- Onboard and groundstation firmware updated for the new electronics
- Major GUI rework, including the map/location view and a new COM controller
- Reworked READMEs and documentation

### Removed
- Flight data simulations
- Groundstation Casing

## 2026-01-04

### Added

- schematics and PCB design files for the onboard electronics system
- firmware for the onboard and ground station systems
- library for configuring and using Radiocrafts RC1780HP-RC232 radio modules
- library for encoding and decoding data packets
- graphical user interface for the ground station (receiving only)
- casing design files for the ground station
- 3d models and images of the system
- documentation for all systems

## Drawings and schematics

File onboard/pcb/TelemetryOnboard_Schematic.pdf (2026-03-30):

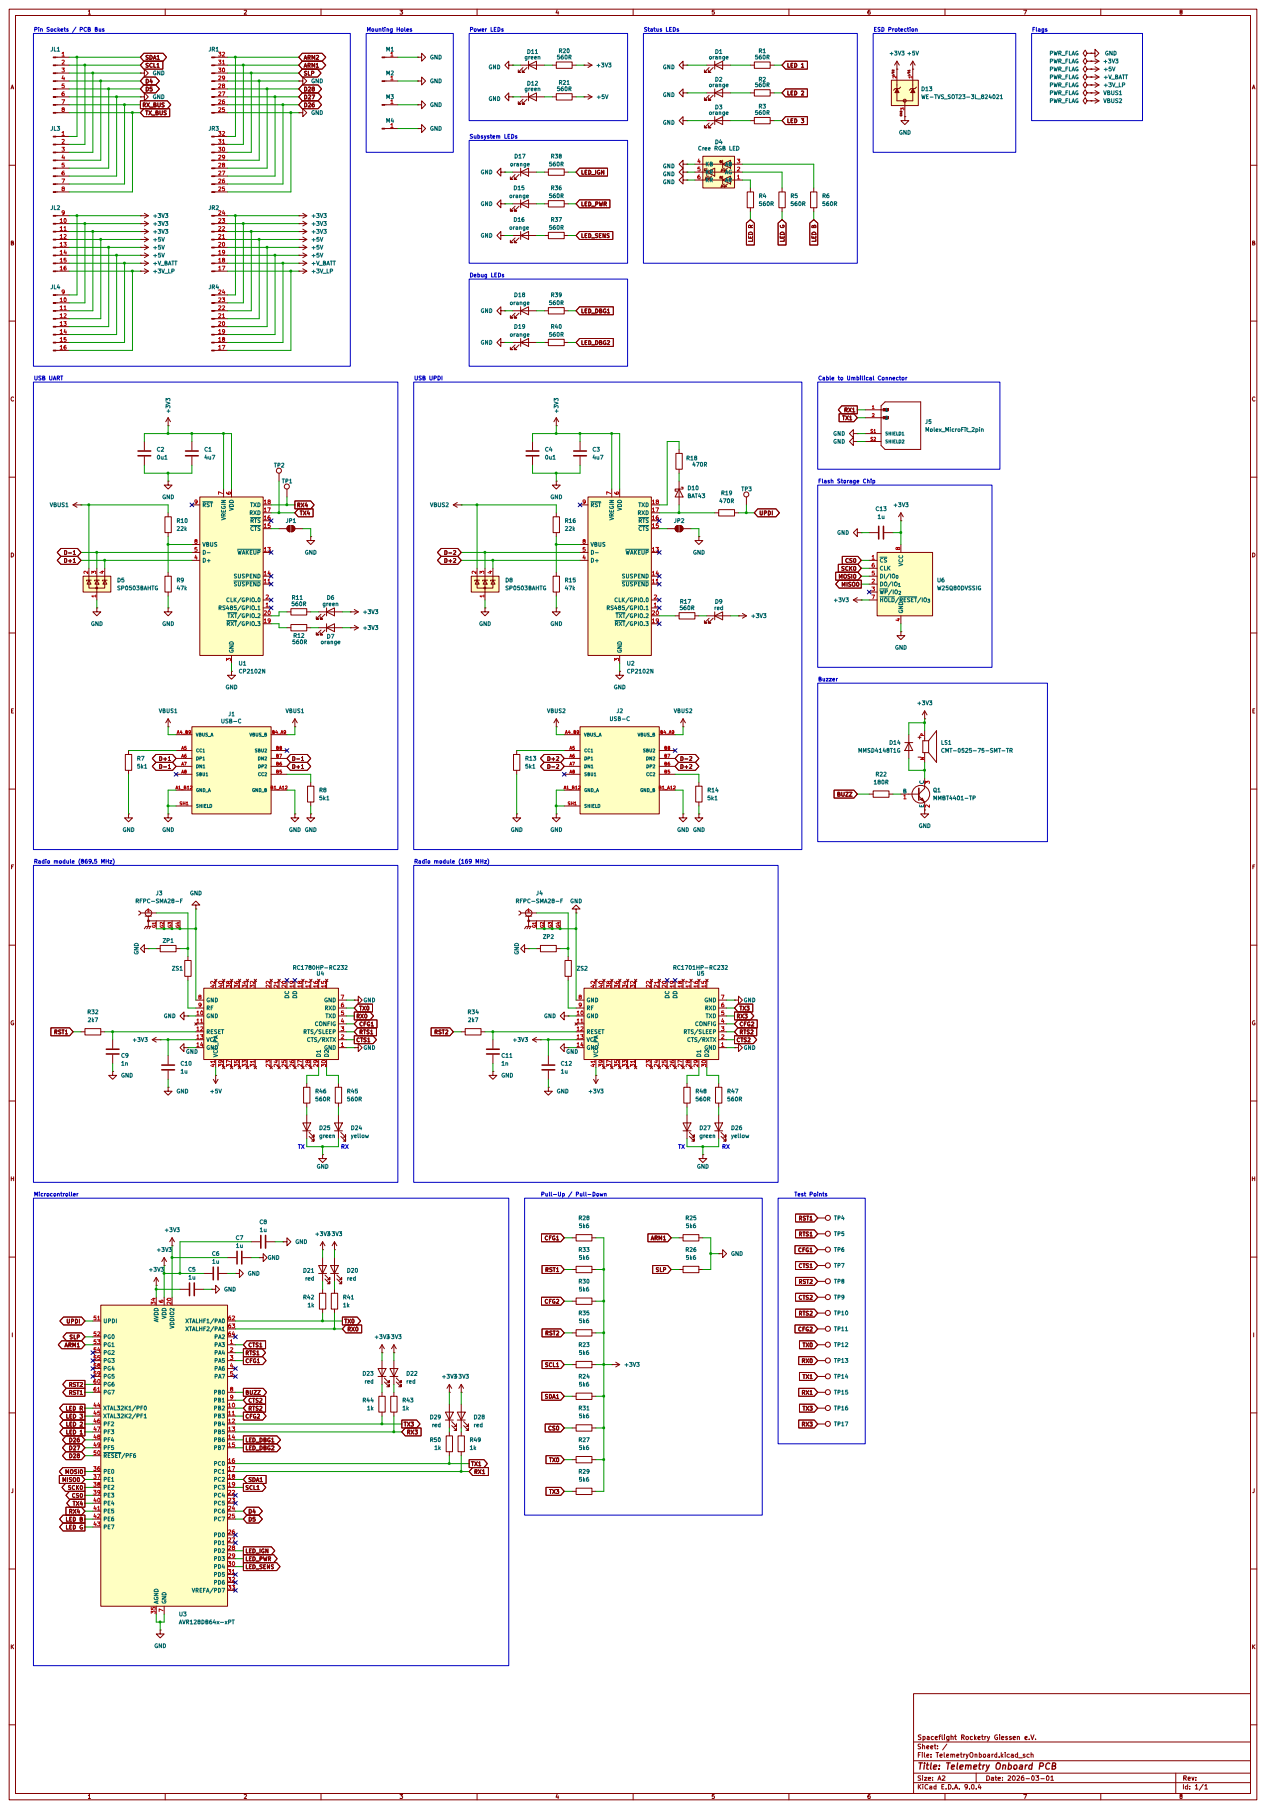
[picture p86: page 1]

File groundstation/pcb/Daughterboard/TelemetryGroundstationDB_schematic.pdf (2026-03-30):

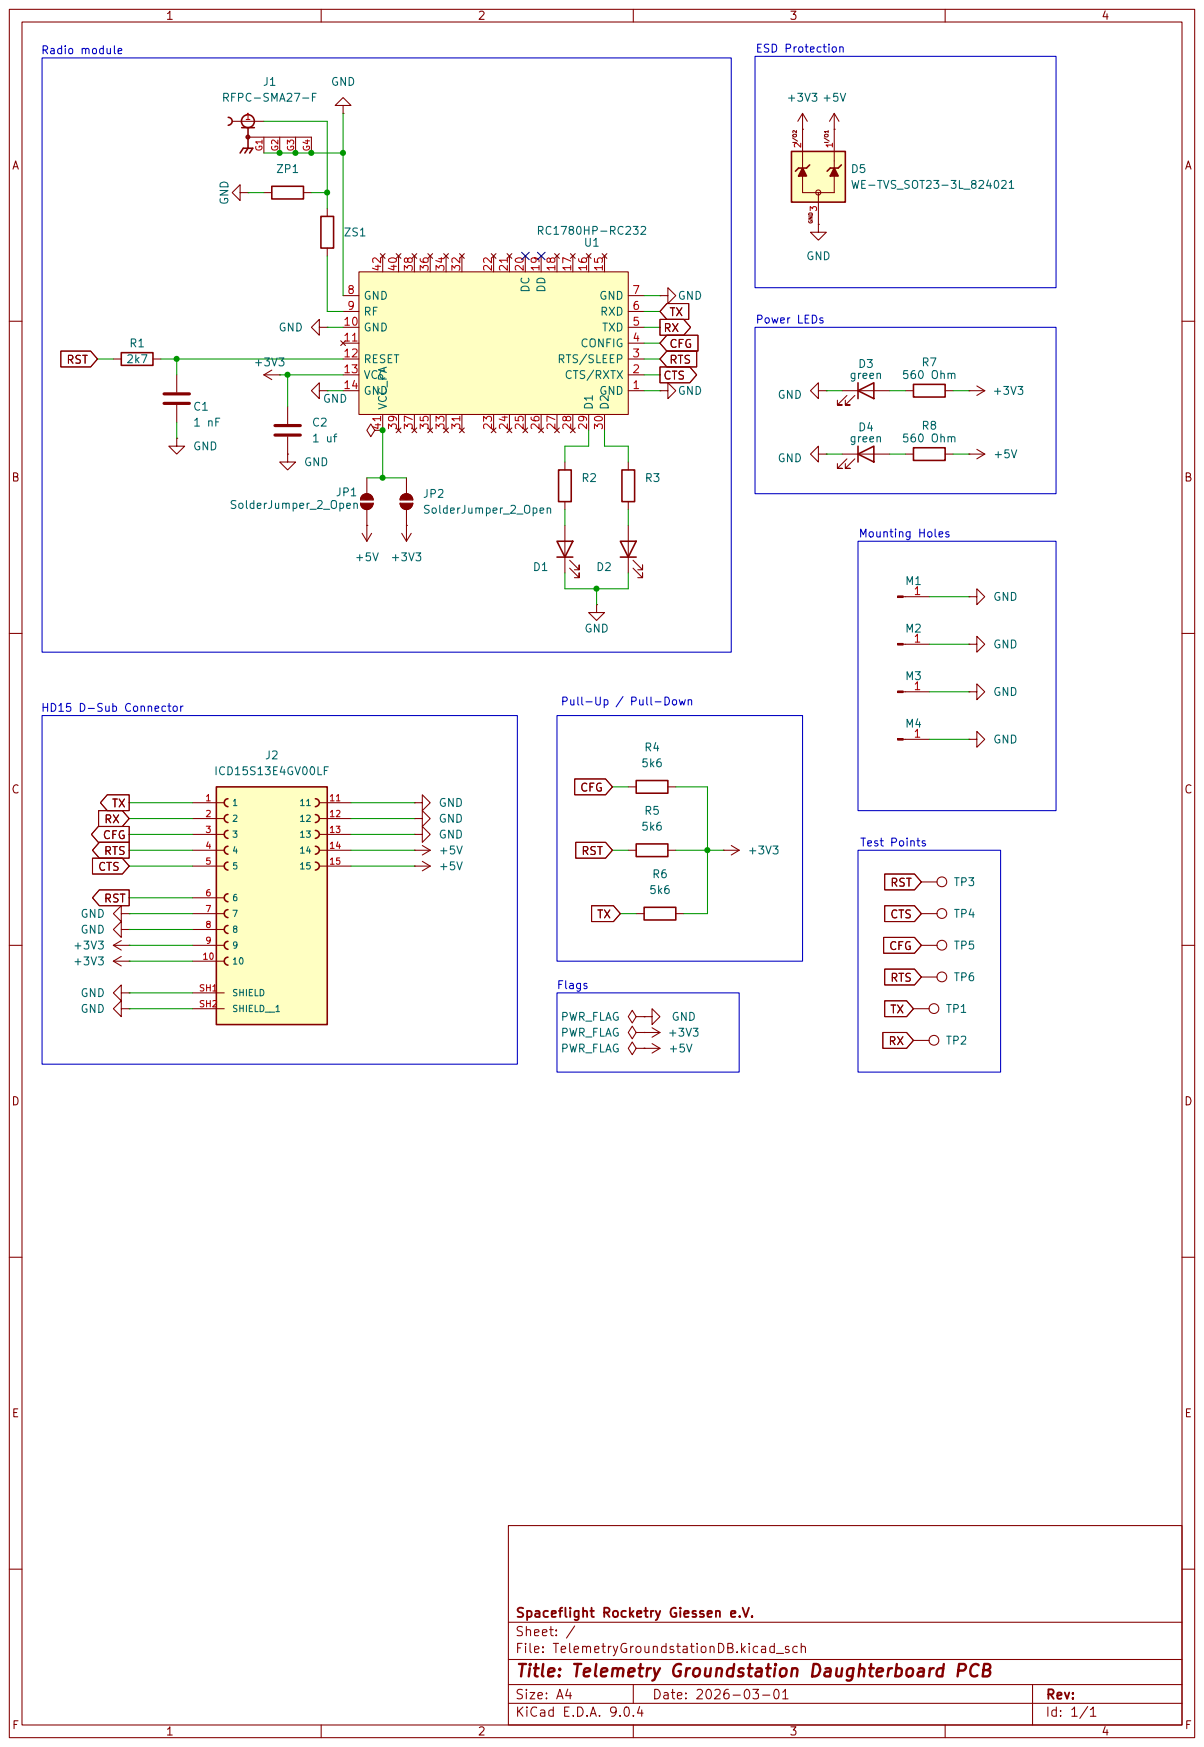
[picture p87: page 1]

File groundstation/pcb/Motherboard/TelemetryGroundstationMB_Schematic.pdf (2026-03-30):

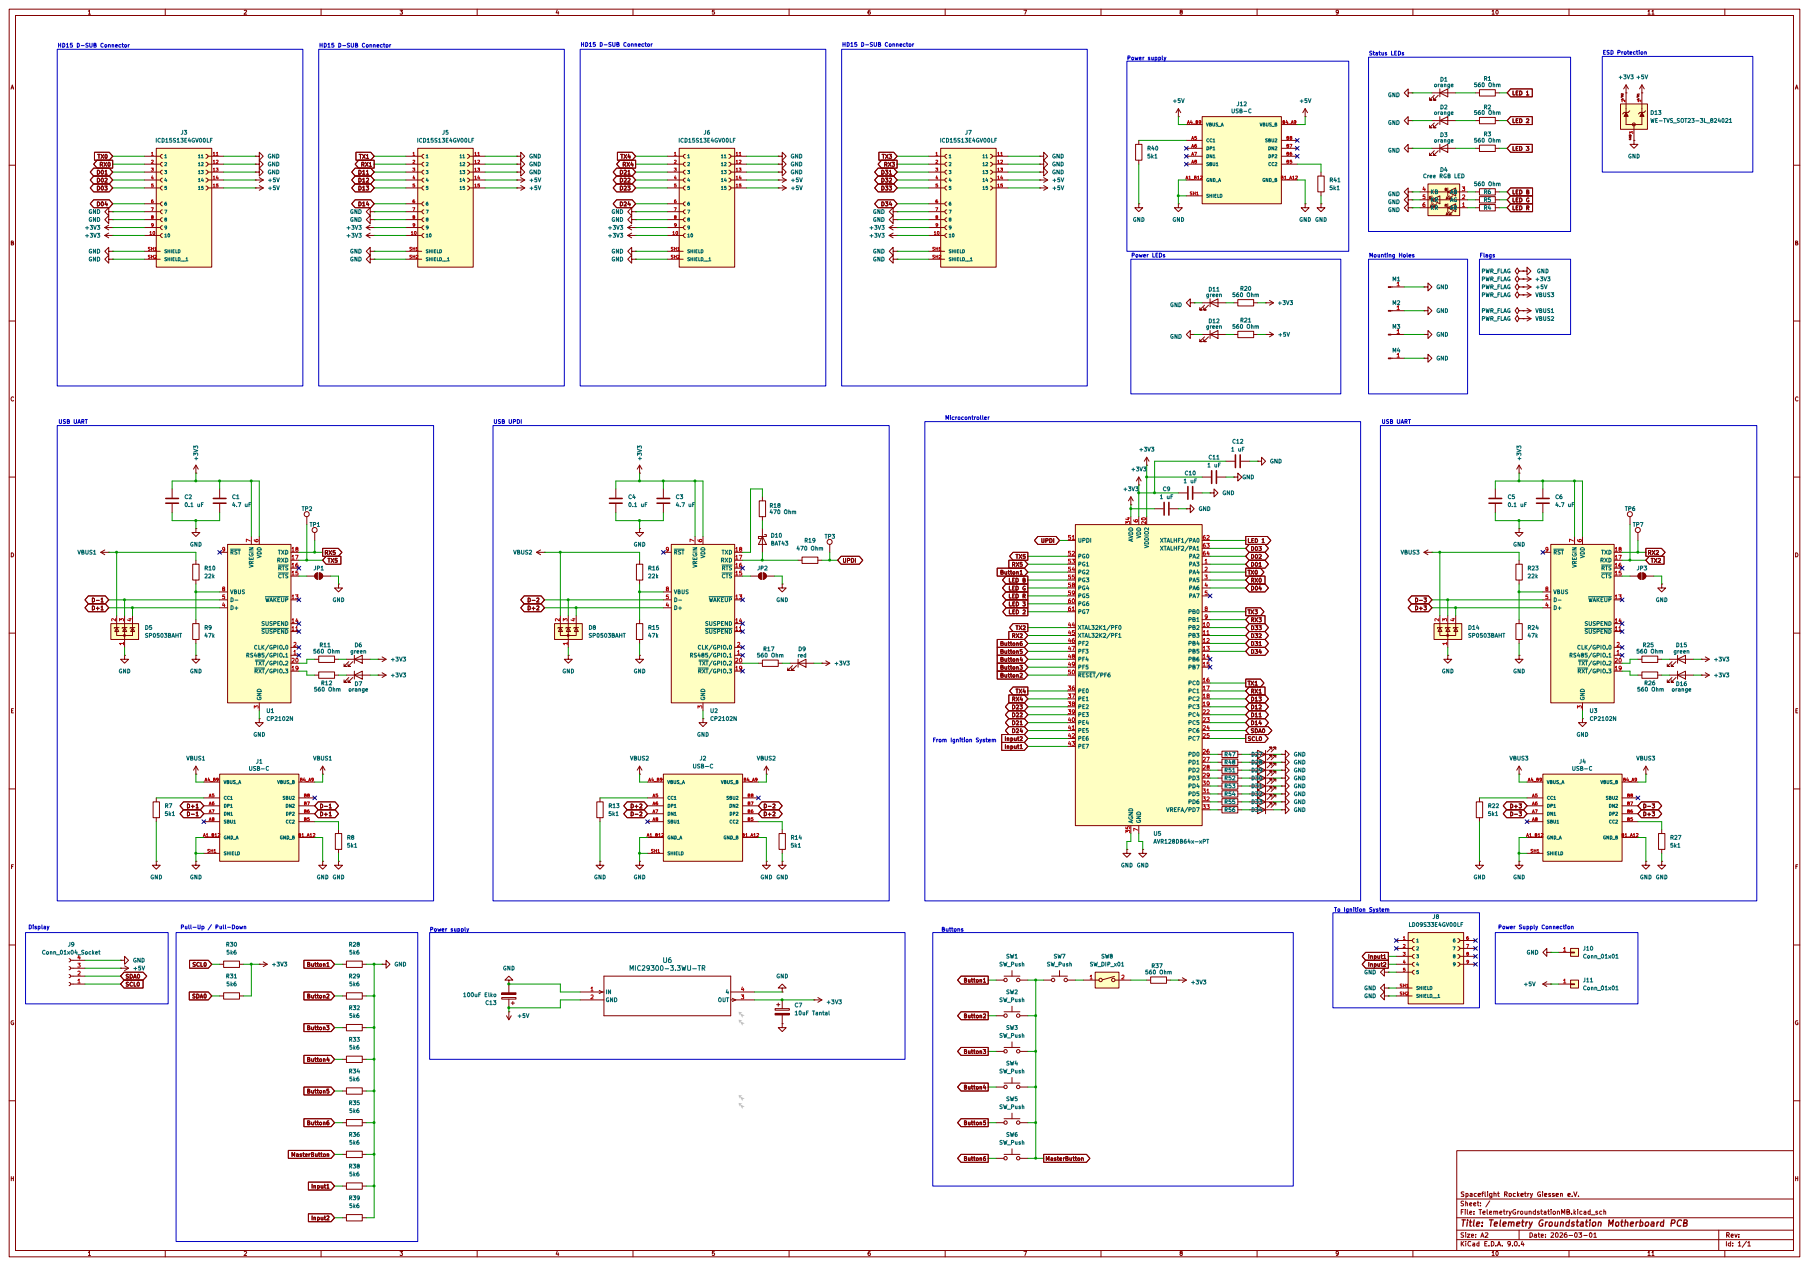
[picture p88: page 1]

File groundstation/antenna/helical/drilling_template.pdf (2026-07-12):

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

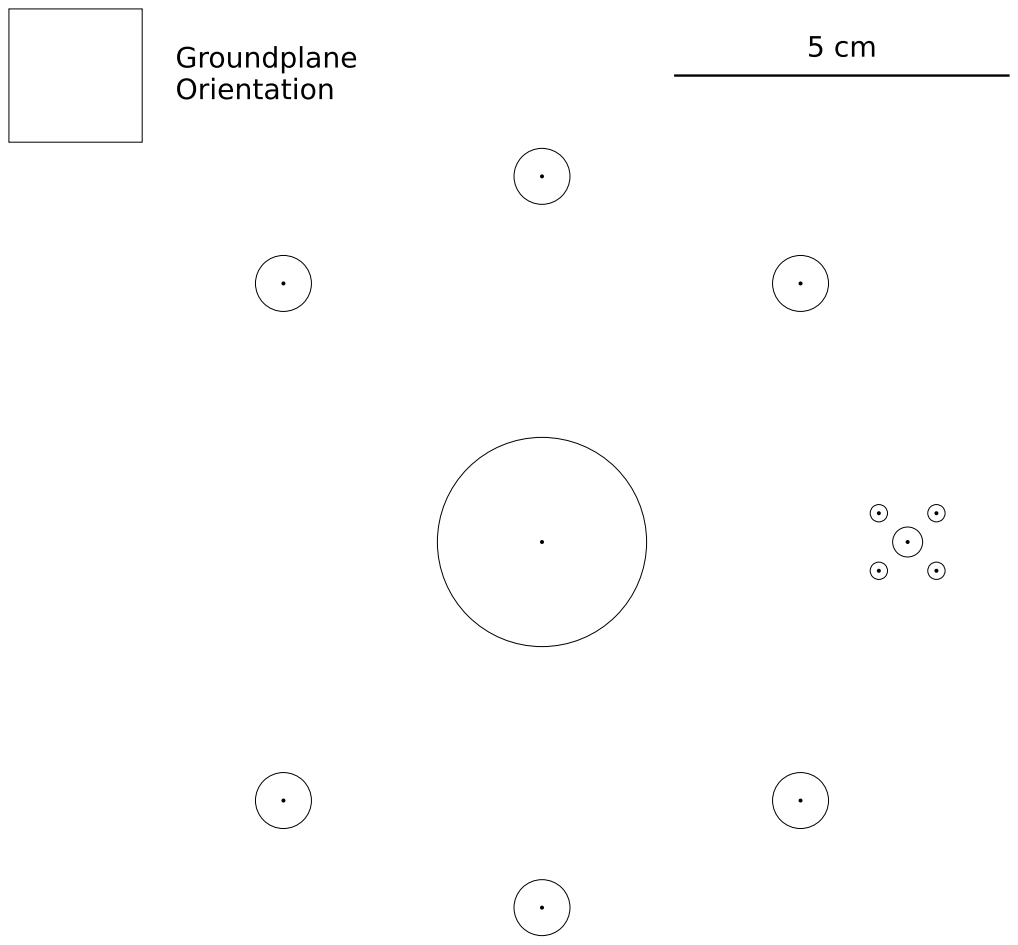
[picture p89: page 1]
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

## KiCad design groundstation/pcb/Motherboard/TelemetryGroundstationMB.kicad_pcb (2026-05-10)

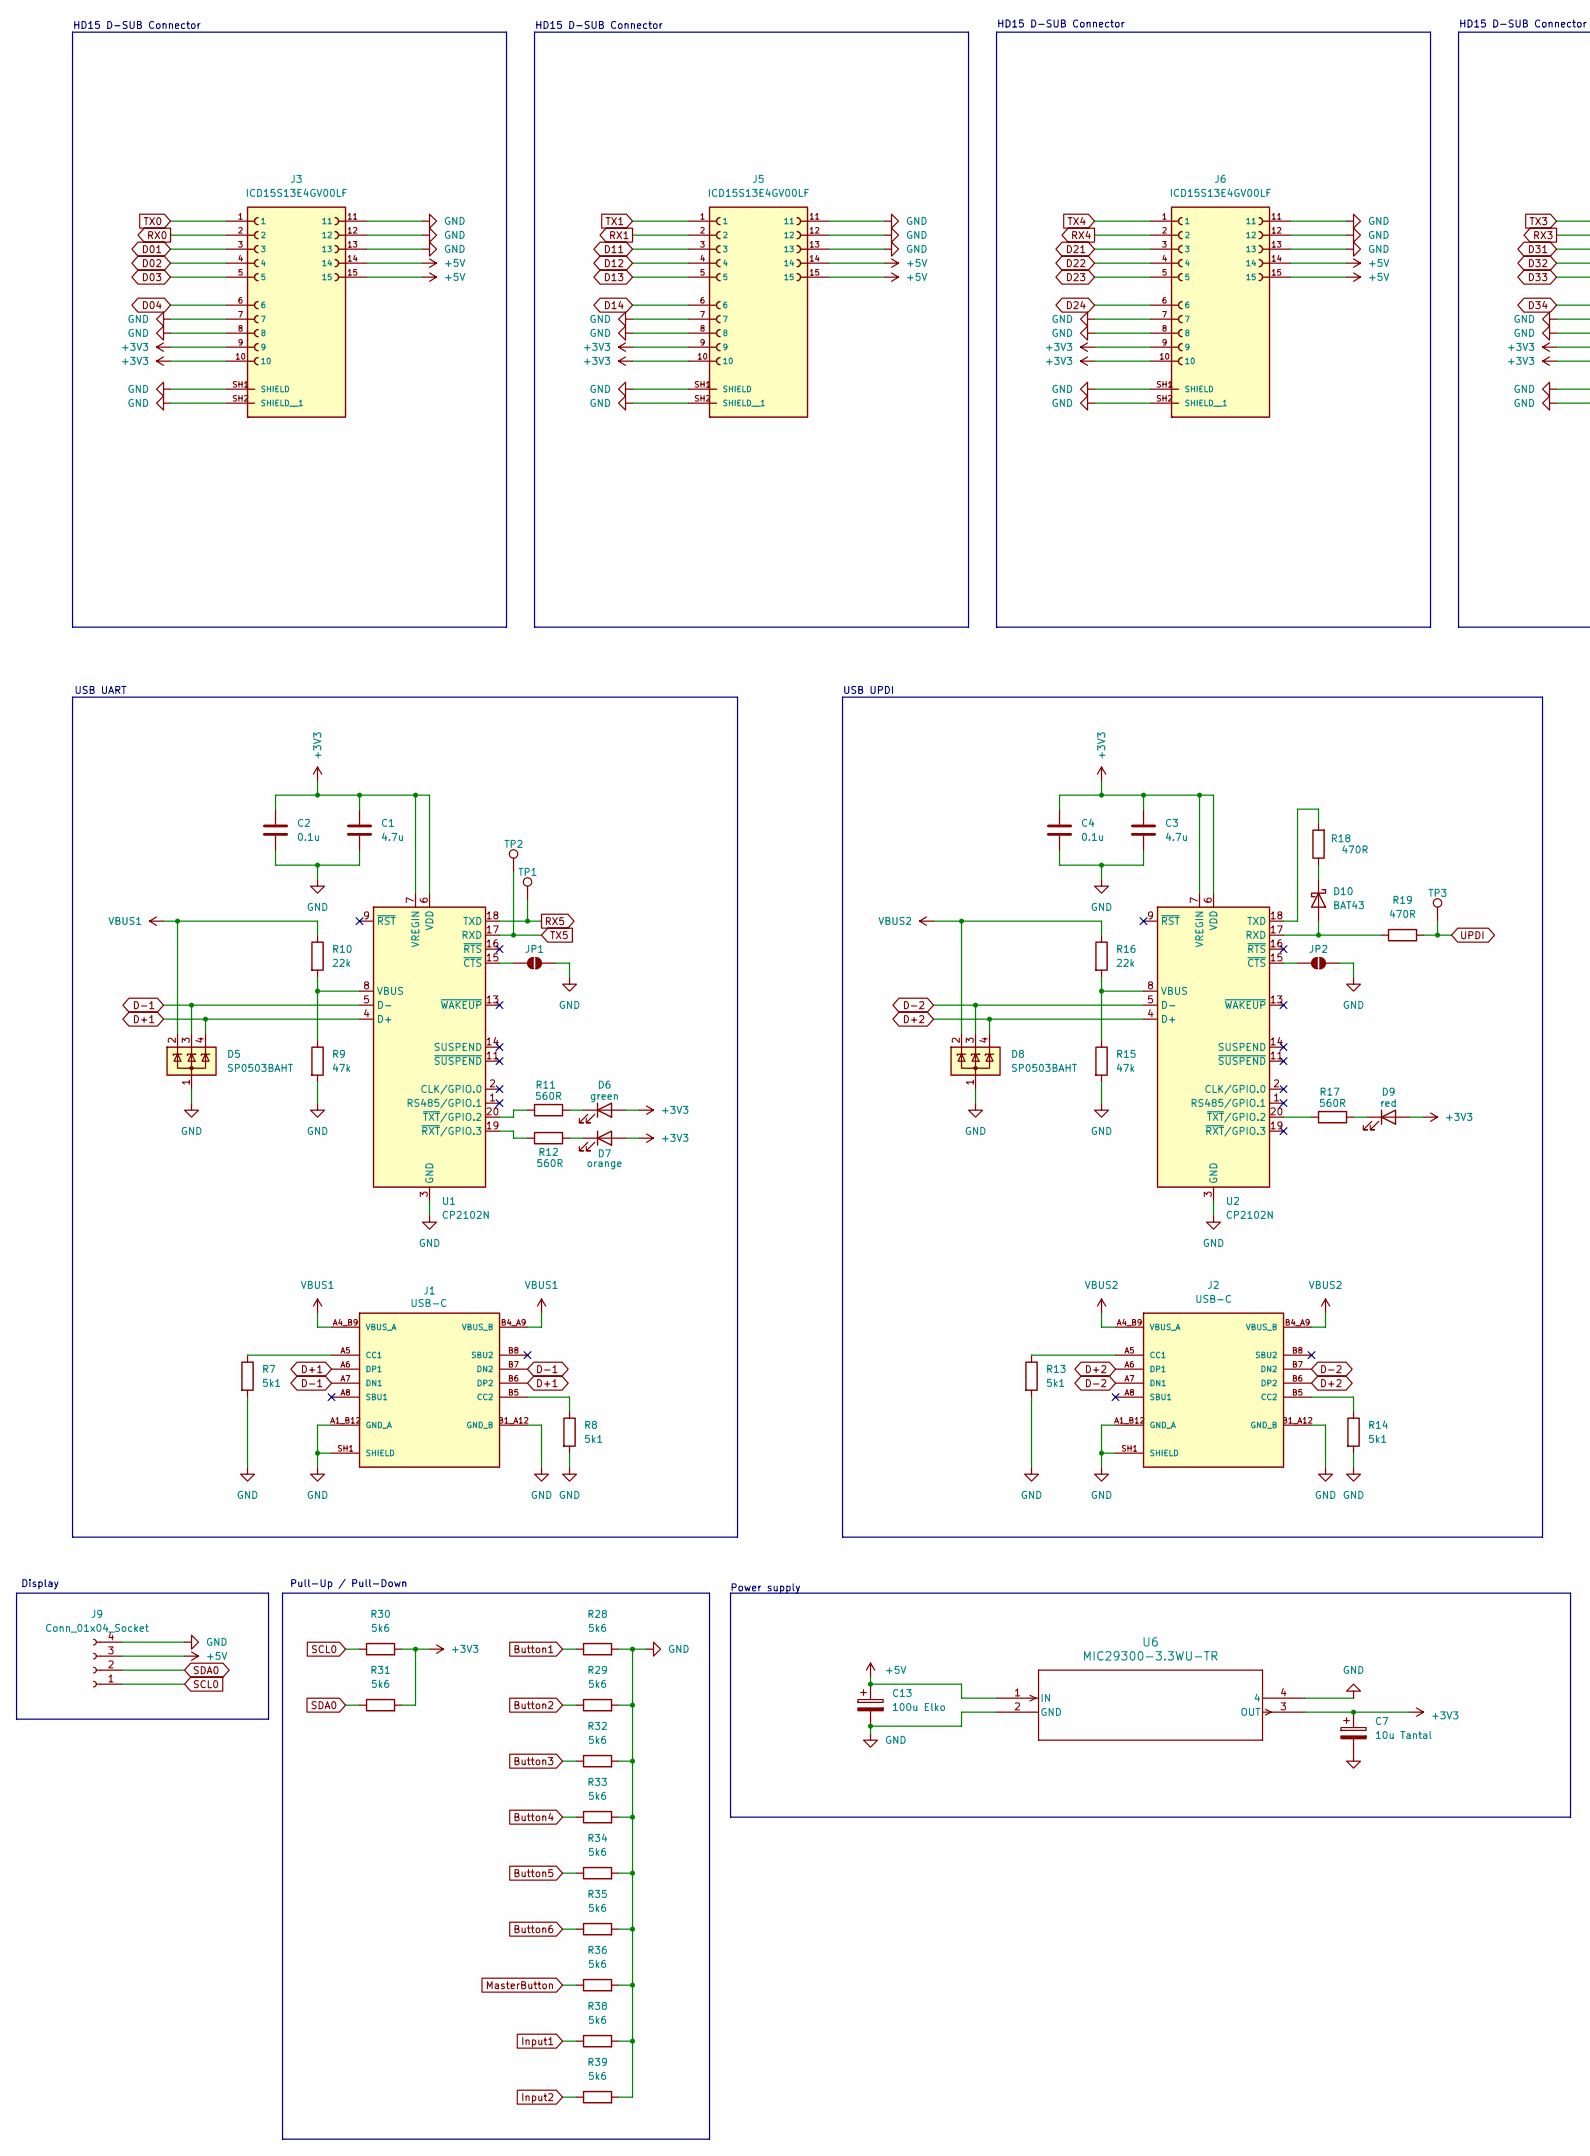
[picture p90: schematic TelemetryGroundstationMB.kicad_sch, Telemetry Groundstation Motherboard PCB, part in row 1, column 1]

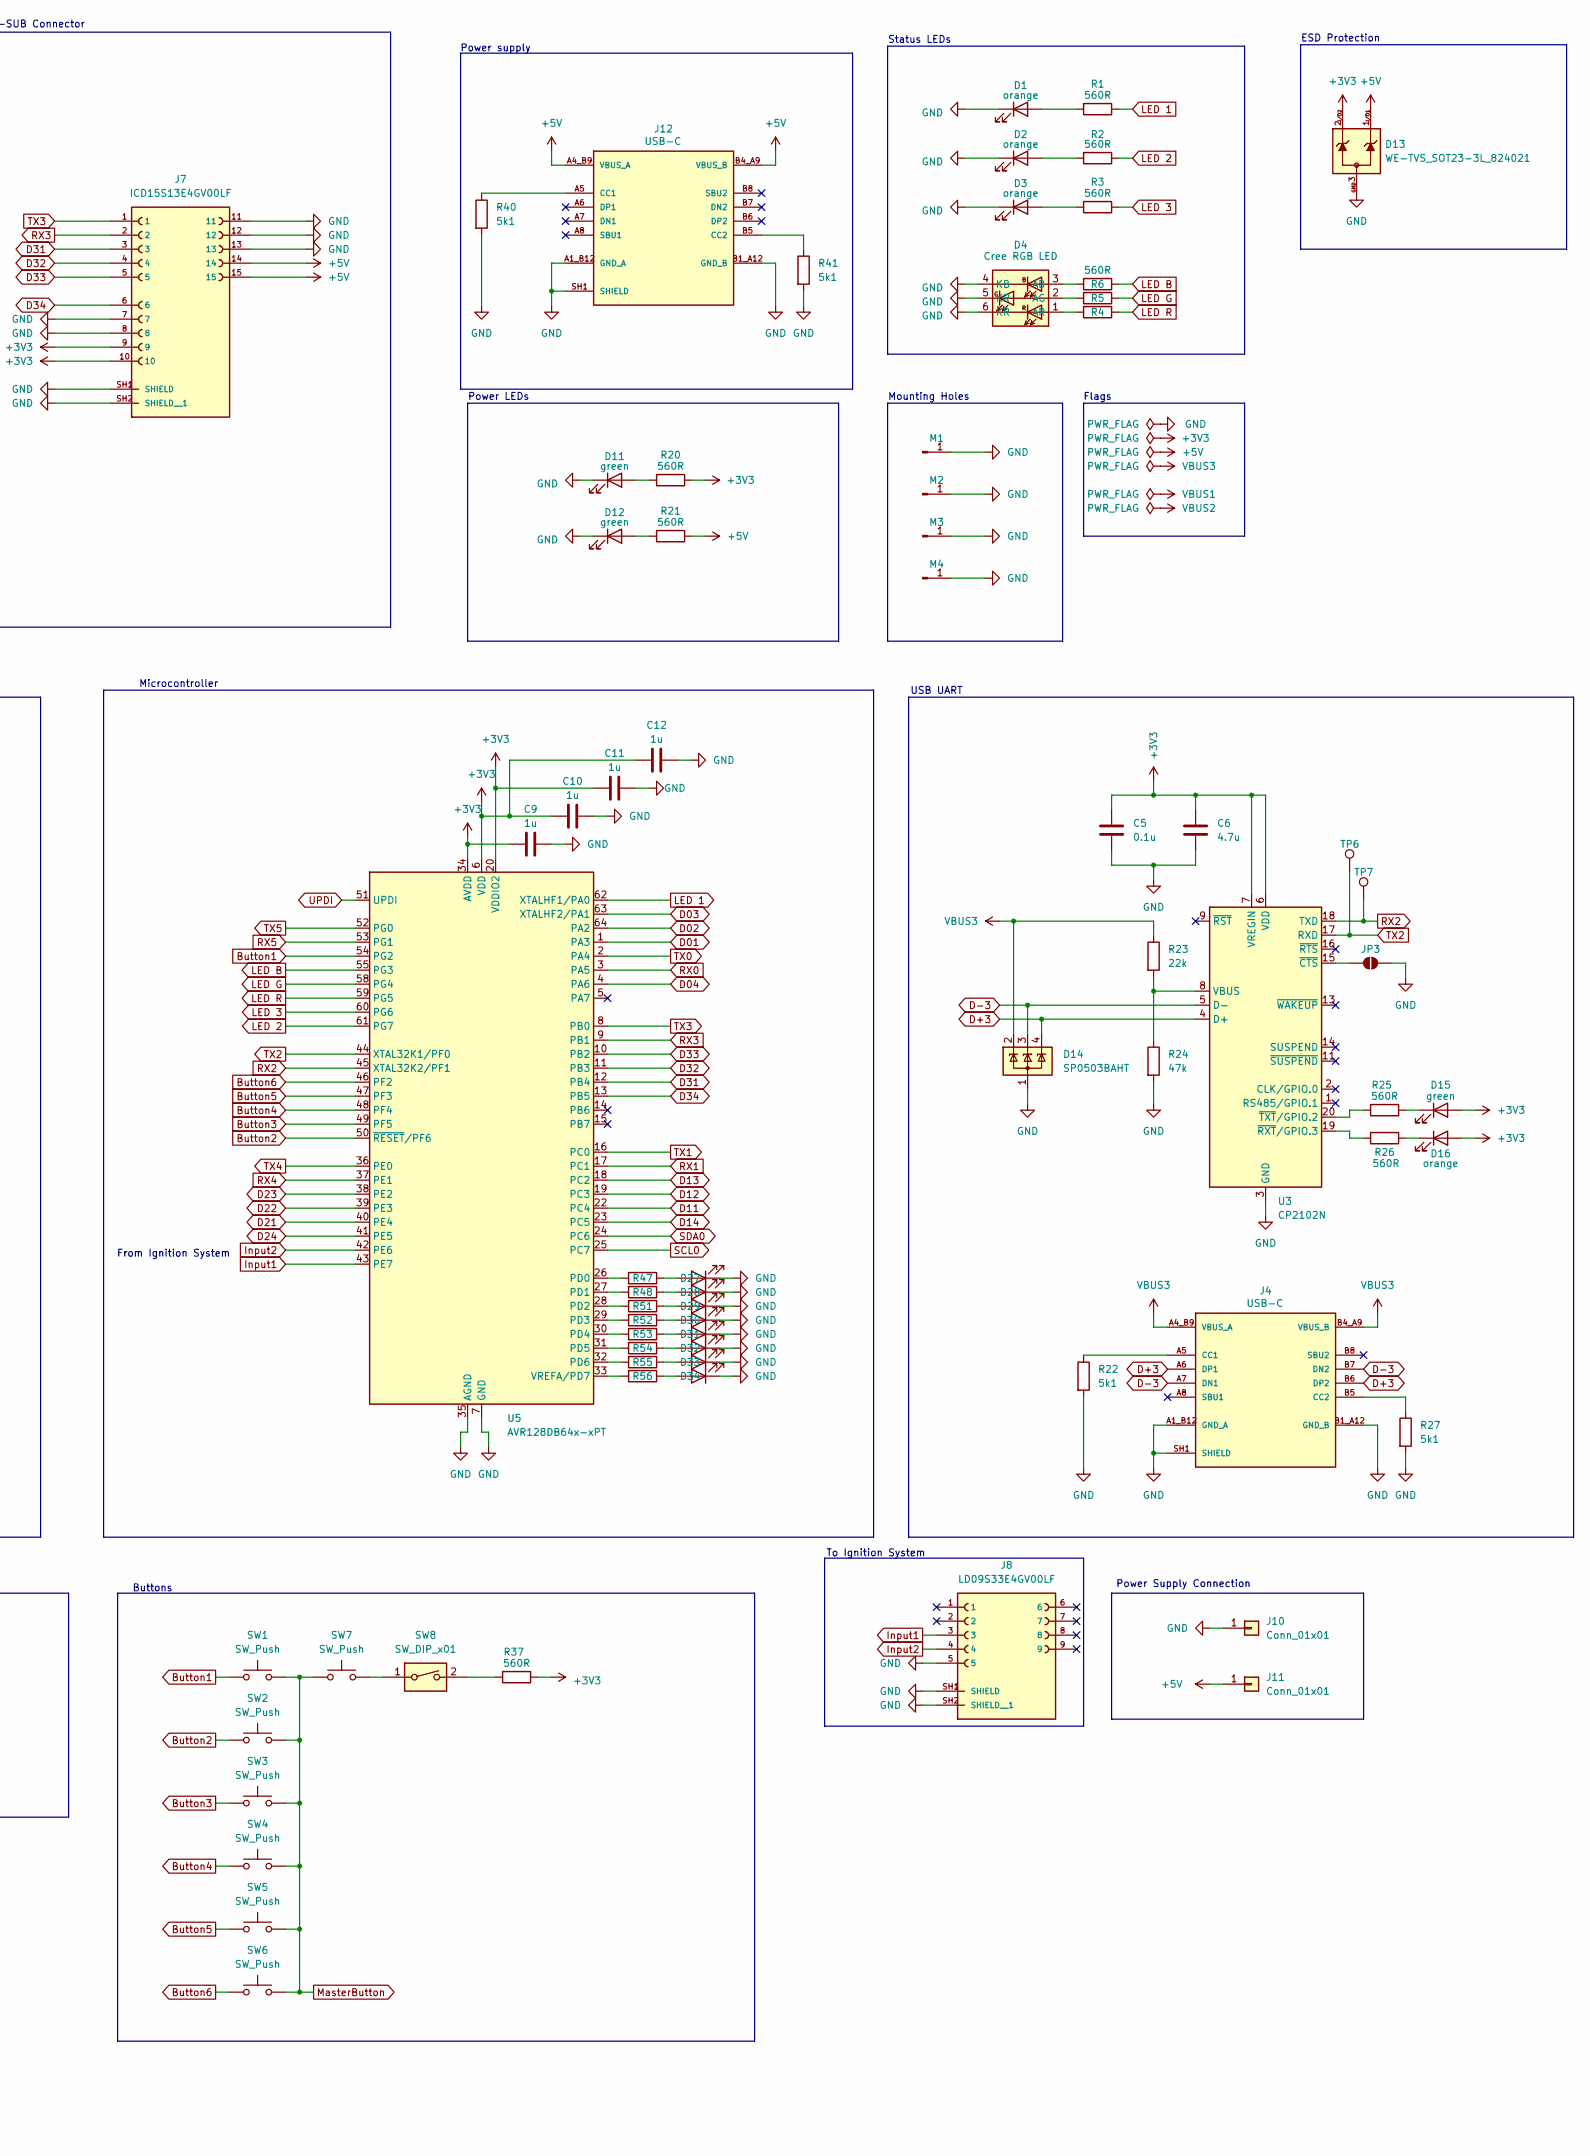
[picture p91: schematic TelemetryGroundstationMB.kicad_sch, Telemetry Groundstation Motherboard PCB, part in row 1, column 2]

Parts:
C1, C3, C6: 4.7u; C_0805_2012Metric_Pad1.18x1.45mm_HandSolder
C2, C4, C5: 0.1u; C_0805_2012Metric_Pad1.18x1.45mm_HandSolder
C7: 10u Tantal; CAPMP3216X180N
C9, C10, C11, C12: 1u; C_0805_2012Metric_Pad1.18x1.45mm_HandSolder
C13: 100u Elko; CP_Radial_D6.3mm_P2.50mm
D1, D2, D3, D7, D16, D27, D28, D29, D30, D31, D32, D33, D34: orange; LED_0805_2012Metric_Pad1.15x1.40mm_HandSolder
D4: Cree RGB LED
D5, D8, D14: SP0503BAHT; SOT-143
D6, D11, D12, D15: green; LED_0805_2012Metric_Pad1.15x1.40mm_HandSolder
D9: red; LED_0805_2012Metric_Pad1.15x1.40mm_HandSolder
D10: BAT43; D_SOD-123
D13: WE-TVS_SOT23-3L_824021; SOT-23-3
J1, J2, J4, J12: USB-C; GCT_USB4216-03-A_REVA; PARTREV A; DigiKey_Part_Number 2073-USB4215-03-ACT-ND
J3, J5, J6, J7: ICD15S13E4GV00LF; AMPHENOL_ICD15S13E4GV00LF[1]; PARTREV G
J8: LD09S33E4GV00LF; AMPHENOL_LD09S33E4GV00LF; PARTREV B
J9: Conn_01x04_Socket; PinSocket_1x04_P2.54mm_Vertical
J10: Conn_01x01; Banana_CT3151-0
J11: Conn_01x01; Banana_CT3151-2
JP1, JP2, JP3: SolderJumper_2_Open; Solder Jumper
M1, M2, M3, M4: M4 Mounting Hole
R1, R2, R3, R4, R5, R6, R11, R12, R17, R20, R21, R25, R26, R37, R47, R48, R51, R52, R53, R54, R55, R56: 560R; R_0805_2012Metric_Pad1.20x1.40mm_HandSolder
R7, R8, R13, R14, R22, R27, R40, R41: 5k1; R_0805_2012Metric_Pad1.20x1.40mm_HandSolder
R9, R15, R24: 47k; R_0805_2012Metric_Pad1.20x1.40mm_HandSolder
R10, R16, R23: 22k; R_0805_2012Metric_Pad1.20x1.40mm_HandSolder
R18, R19: 470R; R_0805_2012Metric_Pad1.20x1.40mm_HandSolder
R28, R29, R30, R31, R32, R33, R34, R35, R36, R38, R39: 5k6; R_0805_2012Metric_Pad1.20x1.40mm_HandSolder
SW1, SW2, SW3, SW4, SW5, SW6, SW7: SW_Push; PinSocket_1x02_P2.54mm_Vertical
SW8: SW_DIP_x01; PinSocket_1x02_P2.54mm_Vertical
TP1, TP2, TP3, TP6, TP7: TestPoint; Test Point
U1, U2, U3: CP2102N; QFN20_CP2102N_SIL
U5: AVR128DB64x-xPT; TQFP-64_10x10mm_P0.5mm
U6: MIC29300-3.3WU-TR; MIC29300

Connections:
+3V3: C1.1, C2.1, C3.1, C4.1, C5.1, C6.1, C7.1, C9.1, C10.1, C11.2, C12.2, D6.2 (A), D7.2 (A), D9.2 (A), D13.2, D15.2 (A), D16.2 (A), J3.9, J3.10, J5.9, J5.10, J6.9, J6.10, J7.9, J7.10, R20.1, R30.2, R31.2, R37.1, U1.6 (VDD), U1.7 (VREGIN), U2.6 (VDD), U2.7 (VREGIN), U3.6 (VDD), U3.7 (VREGIN), U5.6 (VDD), U5.20 (VDDIO2), U5.34 (AVDD), U5.56 (VDD), U6.3 (OUT)
+5V: C13.1, D13.1, J3.14, J3.15, J5.14, J5.15, J6.14, J6.15, J7.14, J7.15, J9.3, J11.1, J12.A4_B9 (VBUS_A), J12.B4_A9 (VBUS_B), R21.1, U6.1 (IN)
Button1: R28.1, SW1.1, U5.54 (PG2)
Button2: R29.1, SW2.1, U5.50 (~RESET/PF6)
Button3: R32.1, SW3.1, U5.49 (PF5)
Button4: R33.1, SW4.1, U5.48 (PF4)
Button5: R34.1, SW5.1, U5.47 (PF3)
Button6: R35.1, SW6.1, U5.46 (PF2)
D01: J3.3, U5.1 (PA3)
D02: J3.4, U5.64 (PA2)
D03: J3.5, U5.63 (XTALHF2/PA1)
D04: J3.6, U5.4 (PA6)
D11: J5.3, U5.22 (PC4)
D12: J5.4, U5.19 (PC3)
D13: J5.5, U5.18 (PC2)
D14: J5.6, U5.23 (PC5)
D21: J6.3, U5.40 (PE4)
D22: J6.4, U5.39 (PE3)
D23: J6.5, U5.38 (PE2)
D24: J6.6, U5.41 (PE5)
D31: J7.3, U5.12 (PB4)
D32: J7.4, U5.11 (PB3)
D33: J7.5, U5.10 (PB2)
D34: J7.6, U5.13 (PB5)
D+1: D5.4 (K), J1.A6 (DP1), J1.B6 (DP2), U1.4 (D+)
D+2: D8.4 (K), J2.A6 (DP1), J2.B6 (DP2), U2.4 (D+)
D+3: D14.4 (K), J4.A6 (DP1), J4.B6 (DP2), U3.4 (D+)
D-1: D5.3 (K), J1.A7 (DN1), J1.B7 (DN2), U1.5 (D-)
D-2: D8.3 (K), J2.A7 (DN1), J2.B7 (DN2), U2.5 (D-)
D-3: D14.3 (K), J4.A7 (DN1), J4.B7 (DN2), U3.5 (D-)
GND: C1.2, C2.2, C3.2, C4.2, C5.2, C6.2, C7.2, C9.2, C10.2, C11.1, C12.1, C13.2, D1.1 (K), D2.1 (K), D3.1 (K), D4.4 (KB), D4.5 (KR), D4.6 (KR), D5.1 (A), D8.1 (A), D11.1 (K), D12.1 (K), D13.3, D14.1 (A), D27.1 (K), D28.1 (K), D29.1 (K), D30.1 (K), D31.1 (K), D32.1 (K), D33.1 (K), D34.1 (K), J1.A1_B12 (GND_A), J1.B1_A12 (GND_B), J1.SH1 (SHIELD), J1.SH2 (SHIELD), J1.SH3 (SHIELD), J1.SH4 (SHIELD), J2.A1_B12 (GND_A), J2.B1_A12 (GND_B), J2.SH1 (SHIELD), J2.SH2 (SHIELD), J2.SH3 (SHIELD), J2.SH4 (SHIELD), J3.7, J3.8, J3.11, J3.12, J3.13, J3.SH1 (SHIELD), J3.SH2 (SHIELD__1), J4.A1_B12 (GND_A), J4.B1_A12 (GND_B), J4.SH1 (SHIELD), J4.SH2 (SHIELD), J4.SH3 (SHIELD), J4.SH4 (SHIELD), J5.7, J5.8, J5.11, J5.12, J5.13, J5.SH1 (SHIELD), J5.SH2 (SHIELD__1), J6.7, J6.8, J6.11, J6.12, J6.13, J6.SH1 (SHIELD), J6.SH2 (SHIELD__1), J7.7, J7.8, J7.11, J7.12, J7.13, J7.SH1 (SHIELD), J7.SH2 (SHIELD__1), J8.5, J8.SH1 (SHIELD), J8.SH2 (SHIELD__1), J9.4, J10.1, J12.A1_B12 (GND_A), J12.B1_A12 (GND_B), J12.SH1 (SHIELD), J12.SH2 (SHIELD), J12.SH3 (SHIELD), J12.SH4 (SHIELD), JP1.2 (B), JP2.2 (B), JP3.2 (B), M1.1, M2.1, M3.1, M4.1, R7.2, R8.2, R9.2, R13.2, R14.2, R15.2, R22.2, R24.2, R27.2, R28.2, R29.2, R32.2, R33.2, R34.2, R35.2, R36.2, R38.2, R39.2, R40.2, R41.2, U1.3 (GND), U1.12 (GND), U1.21 (GND), U2.3 (GND), U2.12 (GND), U2.21 (GND), U3.3 (GND), U3.12 (GND), U3.21 (GND), U5.7 (GND), U5.21 (GND), U5.35 (AGND), U5.57 (GND), U6.2 (GND), U6.4
Input1: J8.3, R38.1, U5.43 (PE7)
Input2: J8.4, R39.1, U5.42 (PE6)
LED 1: R1.1, U5.62 (XTALHF1/PA0)
LED 2: R2.1, U5.61 (PG7)
LED 3: R3.1, U5.60 (PG6)
LED B: R6.1, U5.55 (PG3)
LED G: R5.1, U5.58 (PG4)
LED R: R4.1, U5.59 (PG5)
MasterButton: R36.1, SW1.2, SW2.2, SW3.2, SW4.2, SW5.2, SW6.2, SW7.1
unnamed: D1.2 (A), R1.2
unnamed: D2.2 (A), R2.2
unnamed: D3.2 (A), R3.2
unnamed: D4.3 (AB), R6.2
unnamed: D4.2 (AG), R5.2
unnamed: D4.1 (AR), R4.2
unnamed: D6.1 (K), R11.1
unnamed: D7.1 (K), R12.1
unnamed: D9.1 (K), R17.1
unnamed: D10.2 (A), R19.2, U2.17 (RXD)
unnamed: D10.1 (K), R18.1
unnamed: D11.2 (A), R20.2
unnamed: D12.2 (A), R21.2
unnamed: D15.1 (K), R25.1
unnamed: D16.1 (K), R26.1
unnamed: D27.2 (A), R47.1
unnamed: D28.2 (A), R48.1
unnamed: D29.2 (A), R51.1
unnamed: D30.2 (A), R52.1
unnamed: D31.2 (A), R53.1
unnamed: D32.2 (A), R54.1
unnamed: D33.2 (A), R55.1
unnamed: D34.2 (A), R56.1
unnamed: J1.A5 (CC1), R7.1
unnamed: J1.B5 (CC2), R8.1
unnamed: J2.A5 (CC1), R13.1
unnamed: J2.B5 (CC2), R14.1
unnamed: J4.A5 (CC1), R22.1
unnamed: J4.B5 (CC2), R27.1
unnamed: J12.A5 (CC1), R40.1
unnamed: J12.B5 (CC2), R41.1
unnamed: JP1.1 (A), U1.15 (~CTS)
unnamed: JP2.1 (A), U2.15 (~CTS)
unnamed: JP3.1 (A), U3.15 (~CTS)
unnamed: R37.2, SW8.2
unnamed: SW7.2, SW8.1
unnamed: R9.1, R10.2, U1.8 (VBUS)
unnamed: R12.2, U1.19 (~RXT/GPIO.3)
unnamed: R11.2, U1.20 (~TXT/GPIO.2)
unnamed: R18.2, U2.18 (TXD)
unnamed: R15.1, R16.2, U2.8 (VBUS)
unnamed: R17.2, U2.20 (~TXT/GPIO.2)
unnamed: R23.2, R24.1, U3.8 (VBUS)
unnamed: R26.2, U3.19 (~RXT/GPIO.3)
unnamed: R25.2, U3.20 (~TXT/GPIO.2)
unnamed: R47.2, U5.26 (PD0)
unnamed: R48.2, U5.27 (PD1)
unnamed: R51.2, U5.28 (PD2)
unnamed: R52.2, U5.29 (PD3)
unnamed: R53.2, U5.30 (PD4)
unnamed: R54.2, U5.31 (PD5)
unnamed: R55.2, U5.32 (PD6)
unnamed: R56.2, U5.33 (VREFA/PD7)
RX0: J3.2, U5.3 (PA5)
RX1: J5.2, U5.17 (PC1)
RX2: TP7.1, U3.18 (TXD), U5.45 (XTAL32K2/PF1)
RX3: J7.2, U5.9 (PB1)
RX4: J6.2, U5.37 (PE1)
RX5: TP1.1, U1.18 (TXD), U5.53 (PG1)
SCL0: J9.1, R30.1, U5.25 (PC7)
SDA0: J9.2, R31.1, U5.24 (PC6)
TX0: J3.1, U5.2 (PA4)
TX1: J5.1, U5.16 (PC0)
TX2: TP6.1, U3.17 (RXD), U5.44 (XTAL32K1/PF0)
TX3: J7.1, U5.8 (PB0)
TX4: J6.1, U5.36 (PE0)
TX5: TP2.1, U1.17 (RXD), U5.52 (PG0)
UPDI: R19.1, TP3.1, U5.51 (UPDI)
VBUS1: D5.2 (K), J1.A4_B9 (VBUS_A), J1.B4_A9 (VBUS_B), R10.1
VBUS2: D8.2 (K), J2.A4_B9 (VBUS_A), J2.B4_A9 (VBUS_B), R16.1
VBUS3: D14.2 (K), J4.A4_B9 (VBUS_A), J4.B4_A9 (VBUS_B), R23.1

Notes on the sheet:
HD15 D-SUB Connector
Power Supply Connection
Pull-Up / Pull-Down
Power supply
Microcontroller
Flags
USB UPDI
USB UART
Status LEDs
Mounting Holes
Power LEDs
Display
ESD Protection
To Ignition System
From Ignition System
Buttons

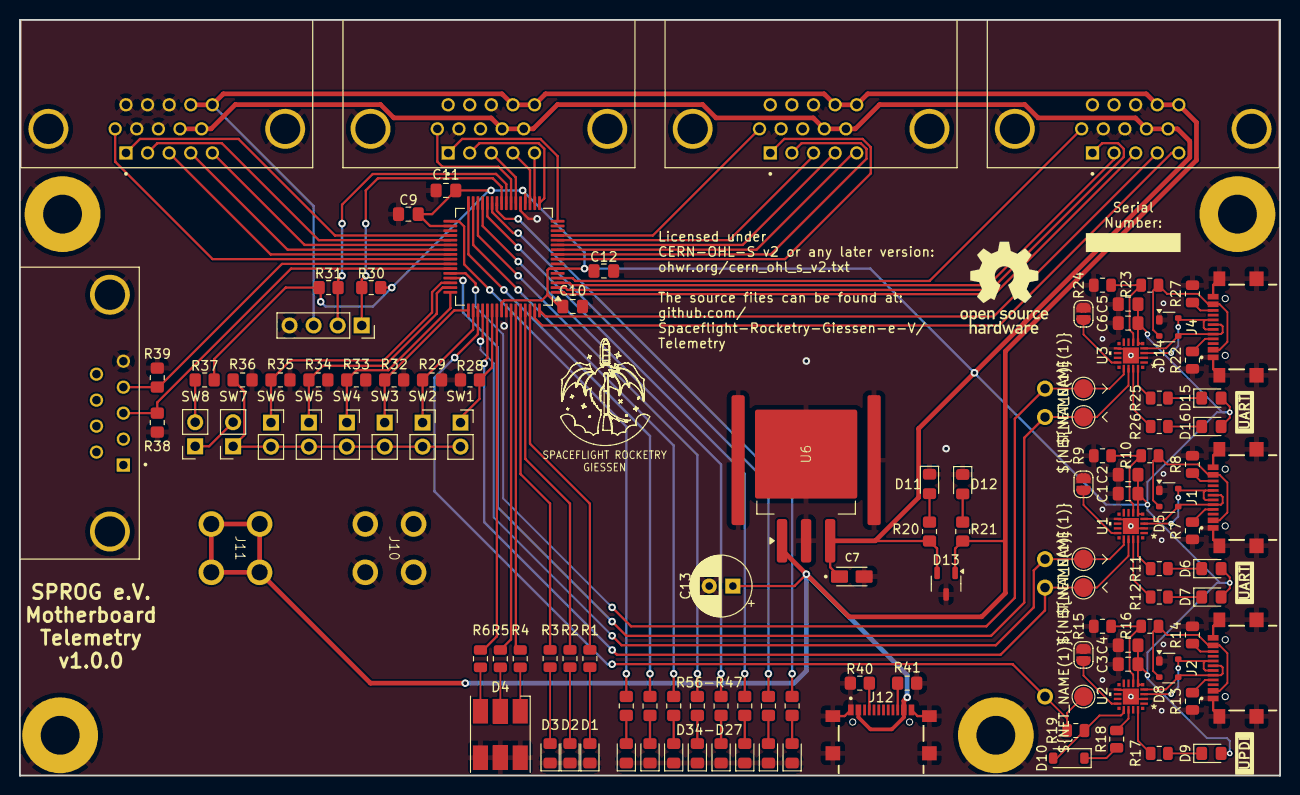
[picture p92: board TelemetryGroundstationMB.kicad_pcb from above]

Board: 2 copper layers, 133.0 x 79.8 mm, 122 parts (0 on the bottom side), 111 nets.

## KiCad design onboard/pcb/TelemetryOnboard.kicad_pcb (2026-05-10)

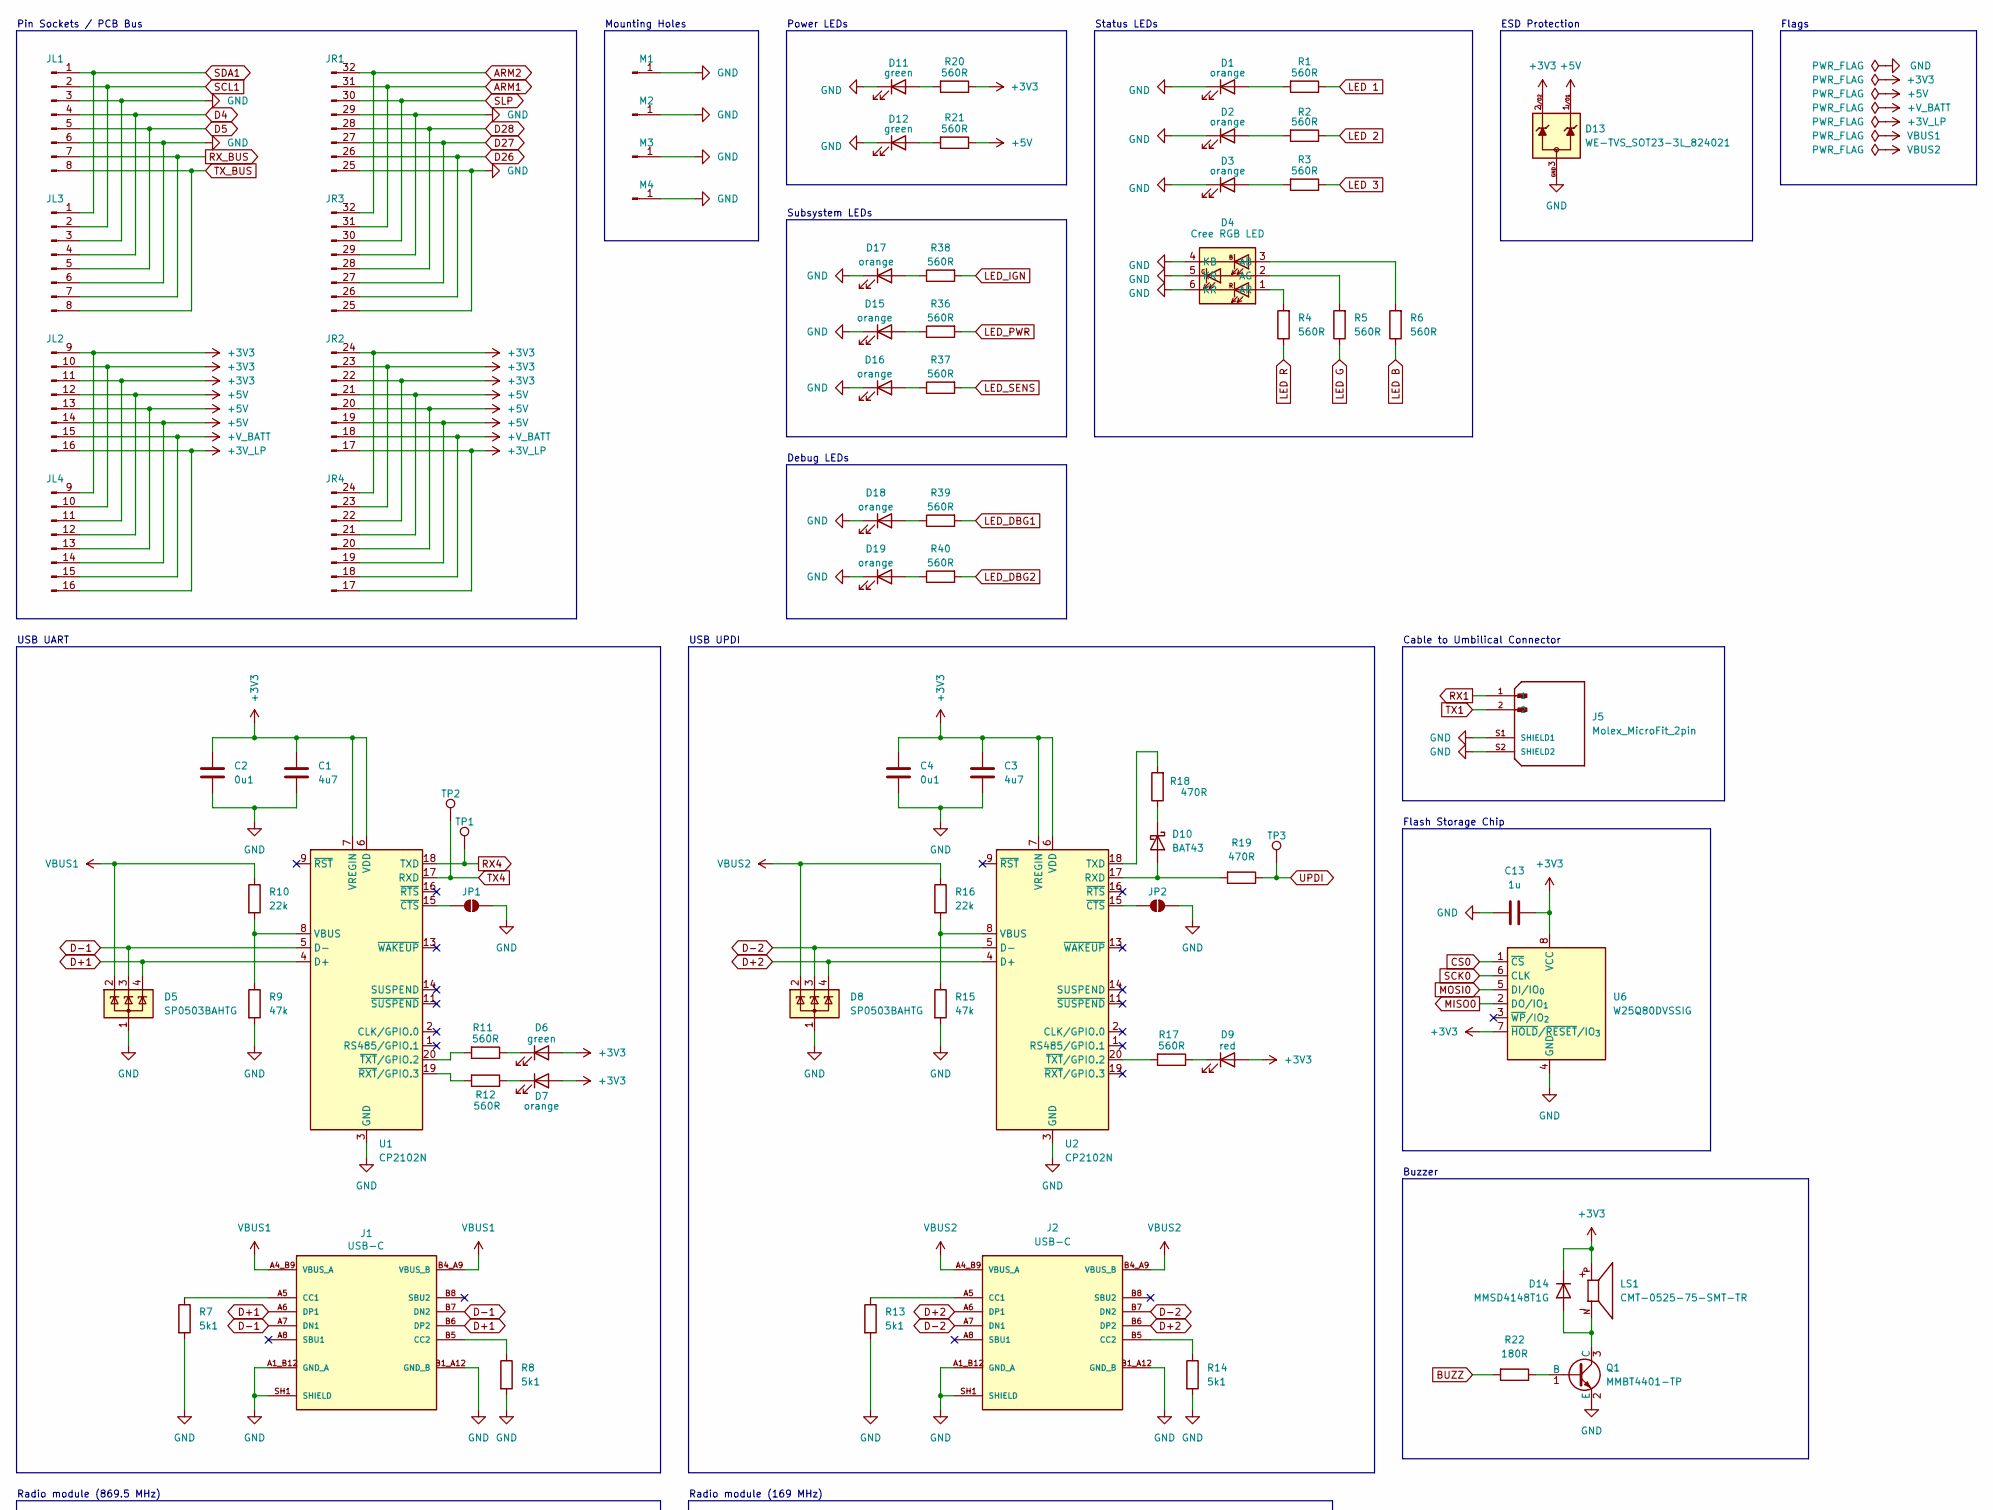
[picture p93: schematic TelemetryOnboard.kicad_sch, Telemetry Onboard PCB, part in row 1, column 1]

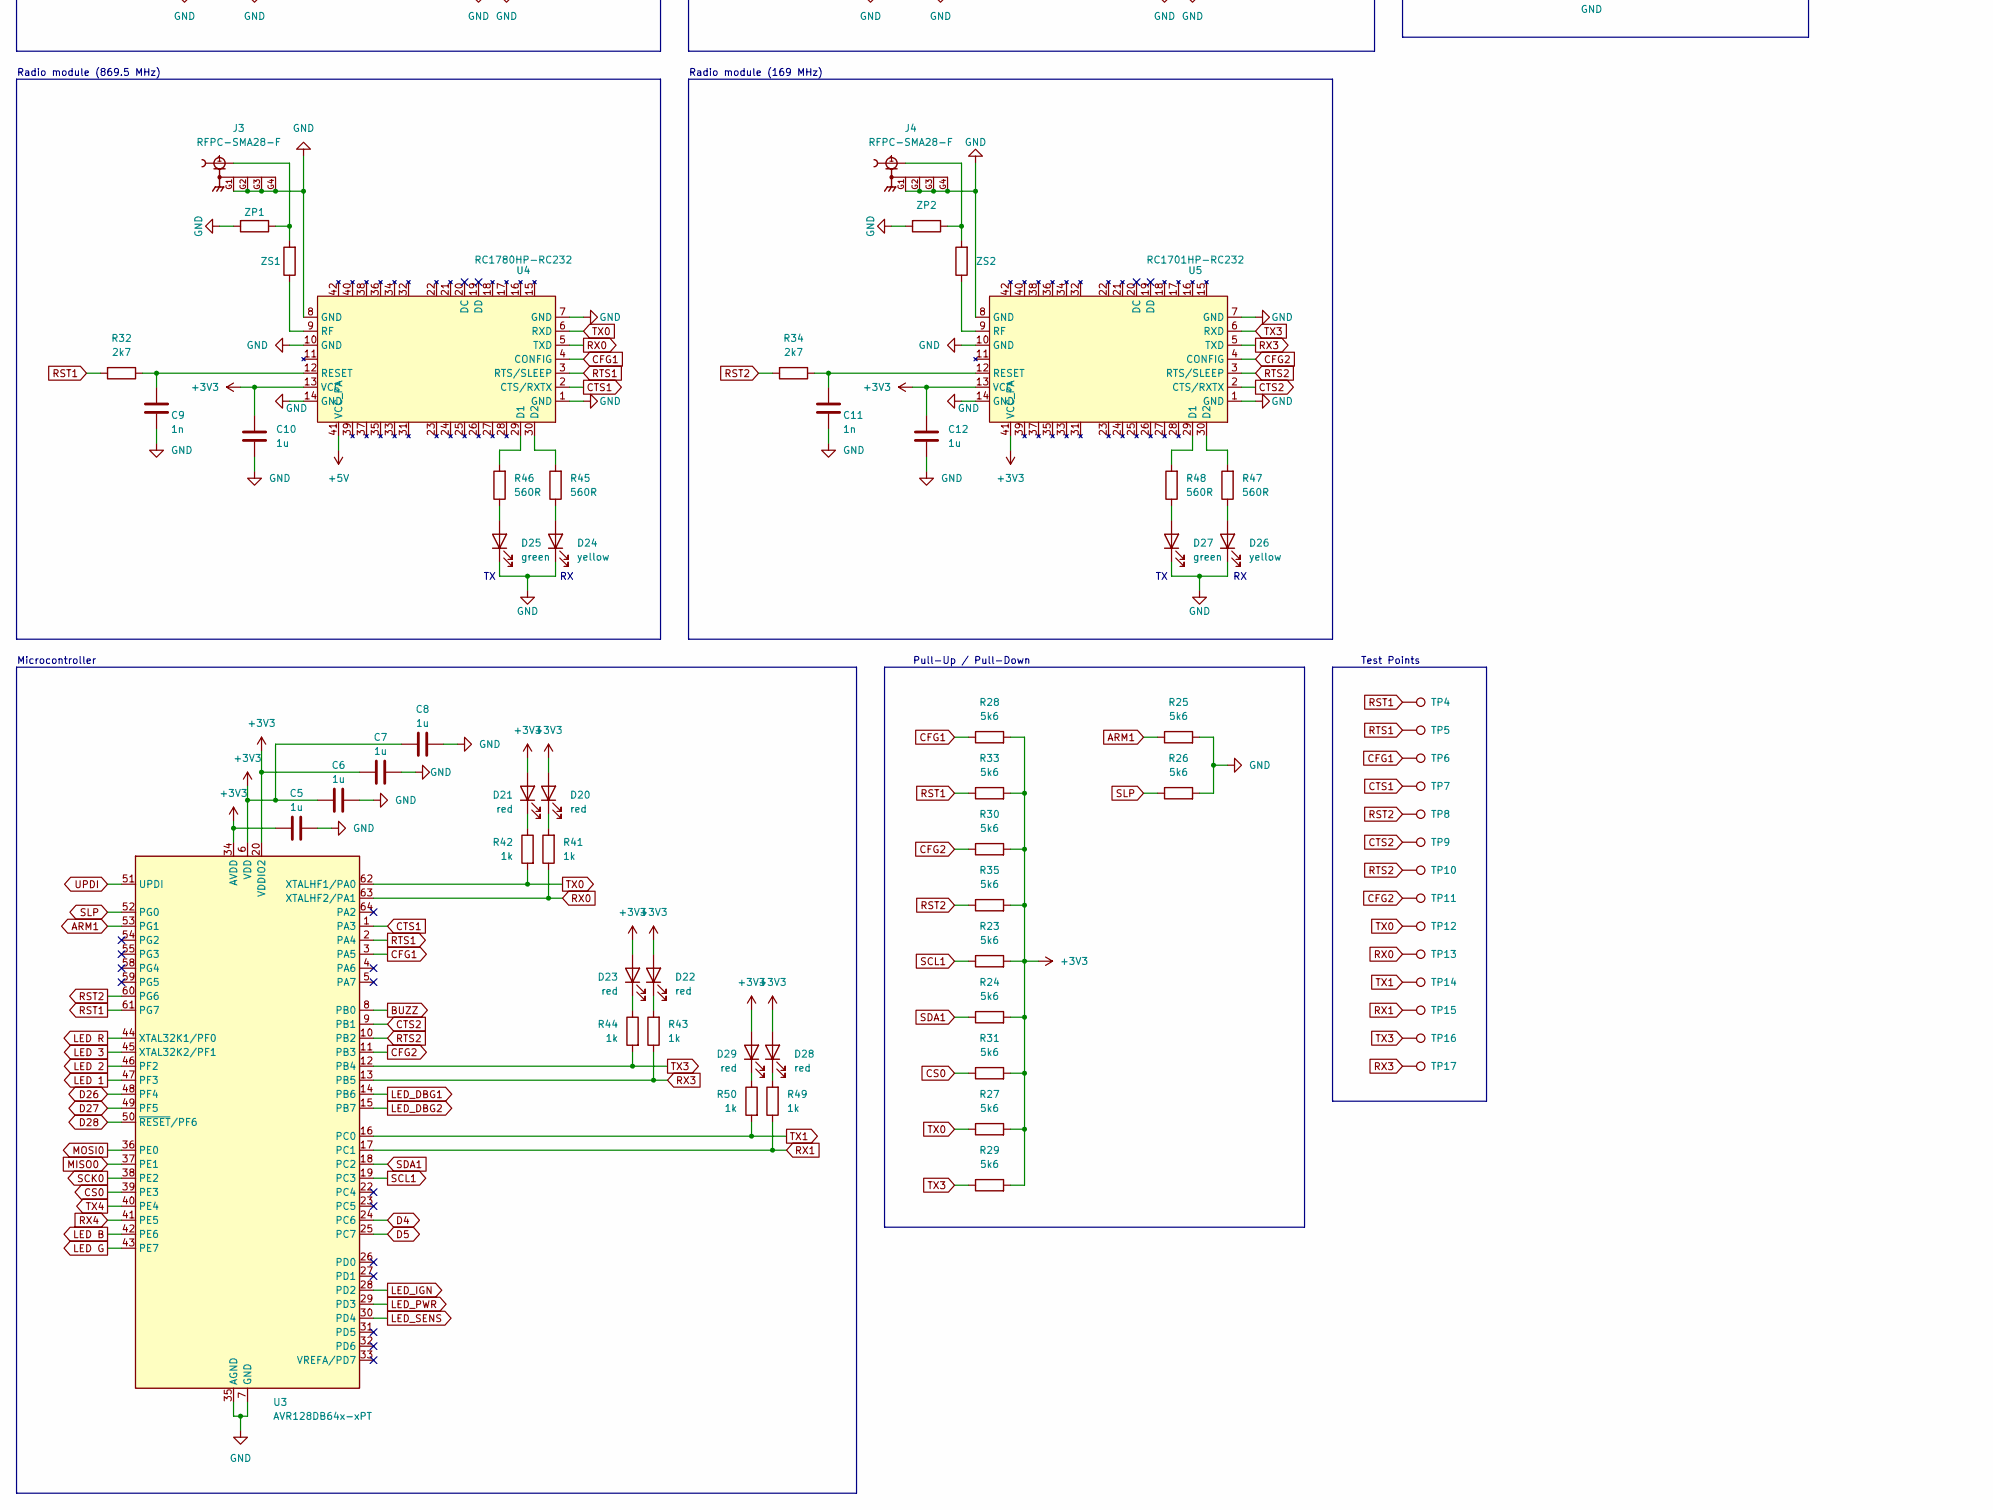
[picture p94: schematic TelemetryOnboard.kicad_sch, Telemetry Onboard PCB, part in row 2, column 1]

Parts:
C1, C3: 4u7; C_0805_2012Metric_Pad1.18x1.45mm_HandSolder
C2, C4: 0u1; C_0805_2012Metric_Pad1.18x1.45mm_HandSolder
C5, C6, C7, C8, C10, C12, C13: 1u; C_0805_2012Metric_Pad1.18x1.45mm_HandSolder
C9, C11: 1n; C_0805_2012Metric_Pad1.18x1.45mm_HandSolder
D1, D2, D3, D7, D15, D16, D17, D18, D19: orange; LED_0805_2012Metric_Pad1.15x1.40mm_HandSolder
D4: Cree RGB LED
D5, D8: SP0503BAHTG; SOT-143
D6, D11, D12, D25, D27: green; LED_0805_2012Metric_Pad1.15x1.40mm_HandSolder
D9, D20, D21, D22, D23, D28, D29: red; LED_0805_2012Metric_Pad1.15x1.40mm_HandSolder
D10: BAT43; D_SOD-123
D13: WE-TVS_SOT23-3L_824021; SOT-23-3
D14: MMSD4148T1G; D_SOD-123
D24, D26: yellow; LED_0805_2012Metric_Pad1.15x1.40mm_HandSolder
J1, J2: USB-C; GCT_USB4216-03-A_REVA; PARTREV A; DigiKey_Part_Number 2073-USB4215-03-ACT-ND
J3, J4: RFPC-SMA28-F; PARTREV 1.0; DigiKey_Part_Number 2073-RFPC-SMA28-F-ND
J5: Molex_MicroFit_2pin; PARTREV F3; DigiKey_Part_Number WM1870-ND
JL1: Stackable Socket 1x8; JL1
JL2: Stackable Socket 1x8; JL2
JL3: Stackable Socket 1x8; JL3
JL4: Stackable Socket 1x8; JL4
JP1, JP2: SolderJumper_2_Open; Solder Jumper
JR1: Stackable Socket 1x8; JR1
JR2: Stackable Socket 1x8; JR2
JR3: Stackable Socket 1x8; JR3
JR4: Stackable Socket 1x8; JR4
LS1: CMT-0525-75-SMT-TR; Buzzer XDCR_CMT-0525-75-SMT-TR; PARTREV 1.0
M1, M2, M3, M4: M4 Mounting Hole
Q1: MMBT4401-TP; SOT-23
R1, R2, R3, R4, R5, R6, R11, R12, R17, R20, R21, R36, R37, R38, R39, R40, R45, R46, R47, R48: 560R; R_0805_2012Metric_Pad1.20x1.40mm_HandSolder
R7, R8, R13, R14: 5k1; R_0805_2012Metric_Pad1.20x1.40mm_HandSolder
R9, R15: 47k; R_0805_2012Metric_Pad1.20x1.40mm_HandSolder
R10, R16: 22k; R_0805_2012Metric_Pad1.20x1.40mm_HandSolder
R18, R19: 470R; R_0805_2012Metric_Pad1.20x1.40mm_HandSolder
R22: 180R; R_0805_2012Metric_Pad1.20x1.40mm_HandSolder
R23, R24, R25, R26, R27, R28, R29, R30, R31, R33, R35: 5k6; R_0805_2012Metric_Pad1.20x1.40mm_HandSolder
R32, R34: 2k7; R_0805_2012Metric_Pad1.20x1.40mm_HandSolder
R41, R42, R43, R44, R49, R50: 1k; R_0805_2012Metric_Pad1.20x1.40mm_HandSolder
TP1, TP2, TP3, TP4, TP5, TP6, TP7, TP8, TP9, TP10, TP11, TP12, TP13, TP14, TP15, TP16, TP17: TestPoint; Test Point
U1, U2: CP2102N; QFN20_CP2102N_SIL
U3: AVR128DB64x-xPT; TQFP-64_10x10mm_P0.5mm
U4: RC1780HP-RC232; Radiocrafts RC1780HP-RC232
U5: RC1701HP-RC232; Radiocrafts RC1780HP-RC232
U6: W25Q80DVSSIG; SOIC-8_5.3x5.3mm_P1.27mm
ZP1, ZP2: R_0805_2012Metric_Pad1.20x1.40mm_HandSolder
ZS1, ZS2: R_0805_2012Metric_Pad1.20x1.40mm_HandSolder

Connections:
+3V3: C1.1, C2.1, C3.1, C4.1, C5.1, C6.1, C7.2, C8.2, C10.1, C12.1, C13.2, D6.2 (A), D7.2 (A), D9.2 (A), D13.2, D14.1 (K), D20.2 (A), D21.2 (A), D22.2 (A), D23.2 (A), D28.2 (A), D29.2 (A), JL2.9 (Pin_1), JL2.10 (Pin_2), JL2.11 (Pin_3), JL4.9 (Pin_1), JL4.10 (Pin_2), JL4.11 (Pin_3), JR2.22 (26), JR2.23 (Pin_2), JR2.24 (Pin_1), JR4.22 (26), JR4.23 (Pin_2), JR4.24 (Pin_1), LS1.P, R20.1, R23.2, R24.2, R27.2, R28.2, R29.2, R30.2, R31.2, R33.2, R35.2, U1.6 (VDD), U1.7 (VREGIN), U2.6 (VDD), U2.7 (VREGIN), U3.6 (VDD), U3.20 (VDDIO2), U3.34 (AVDD), U3.56 (VDD), U4.13 (VCC), U5.13 (VCC), U5.41 (VCC_PA), U6.7 (~HOLD/~RESET/IO_{3}), U6.8 (VCC)
+3V_LP: JL2.16 (Pin_8), JL4.16 (Pin_8), JR2.17 (Pin_8), JR4.17 (Pin_8)
+5V: D13.1, JL2.12 (Pin_4), JL2.13 (Pin_5), JL2.14 (Pin_6), JL4.12 (Pin_4), JL4.13 (Pin_5), JL4.14 (Pin_6), JR2.19 (Pin_6), JR2.20 (Pin_5), JR2.21 (Pin_4), JR4.19 (Pin_6), JR4.20 (Pin_5), JR4.21 (Pin_4), R21.1, U4.41 (VCC_PA)
+V_BATT: JL2.15 (Pin_7), JL4.15 (Pin_7), JR2.18 (Pin_7), JR4.18 (Pin_7)
ARM1: JR1.31 (Pin_2), JR3.31 (Pin_2), R25.1, U3.53 (PG1)
ARM2: JR1.32 (Pin_1), JR3.32 (Pin_1)
BUZZ: R22.2, U3.8 (PB0)
CFG1: R28.1, TP6.1, U3.3 (PA5), U4.4 (CONFIG)
CFG2: R30.1, TP11.1, U3.11 (PB3), U5.4 (CONFIG)
CS0: R31.1, U3.39 (PE3), U6.1 (~CS)
CTS1: TP7.1, U3.1 (PA3), U4.2 (CTS/RXTX)
CTS2: TP9.1, U3.9 (PB1), U5.2 (CTS/RXTX)
D4: JL1.4, JL3.4, U3.24 (PC6)
D5: JL1.5, JL3.5, U3.25 (PC7)
D26: JR1.26 (Pin_7), JR3.26 (Pin_7), U3.48 (PF4)
D27: JR1.27 (Pin_6), JR3.27 (Pin_6), U3.49 (PF5)
D28: JR1.28 (Pin_5), JR3.28 (Pin_5), U3.50 (~RESET/PF6)
D+1: D5.4 (K), J1.A6 (DP1), J1.B6 (DP2), U1.4 (D+)
D+2: D8.4 (K), J2.A6 (DP1), J2.B6 (DP2), U2.4 (D+)
D-1: D5.3 (K), J1.A7 (DN1), J1.B7 (DN2), U1.5 (D-)
D-2: D8.3 (K), J2.A7 (DN1), J2.B7 (DN2), U2.5 (D-)
GND: C1.2, C2.2, C3.2, C4.2, C5.2, C6.2, C7.1, C8.1, C9.2, C10.2, C11.2, C12.2, C13.1, D1.1 (K), D2.1 (K), D3.1 (K), D4.4 (KB), D4.5 (KR), D4.6 (KR), D5.1 (A), D8.1 (A), D11.1 (K), D12.1 (K), D13.3, D15.1 (K), D16.1 (K), D17.1 (K), D18.1 (K), D19.1 (K), D24.1 (K), D25.1 (K), D26.1 (K), D27.1 (K), J1.A1_B12 (GND_A), J1.B1_A12 (GND_B), J1.SH1 (SHIELD), J1.SH2 (SHIELD), J1.SH3 (SHIELD), J1.SH4 (SHIELD), J2.A1_B12 (GND_A), J2.B1_A12 (GND_B), J2.SH1 (SHIELD), J2.SH2 (SHIELD), J2.SH3 (SHIELD), J2.SH4 (SHIELD), J3.G1, J3.G2, J3.G3, J3.G4, J4.G1, J4.G2, J4.G3, J4.G4, J5.S1 (SHIELD1), J5.S2 (SHIELD2), JL1.3, JL1.6, JL3.3, JL3.6, JP1.2 (B), JP2.2 (B), JR1.25 (Pin_8), JR1.29 (Pin_4), JR3.25 (Pin_8), JR3.29 (Pin_4), M1.1, M2.1, M3.1, M4.1, Q1.2 (E), R7.2, R8.2, R9.2, R13.2, R14.2, R15.2, R25.2, R26.2, U1.3 (GND), U1.12 (GND), U1.21 (GND), U2.3 (GND), U2.12 (GND), U2.21 (GND), U3.7 (GND), U3.21 (GND), U3.35 (AGND), U3.57 (GND), U4.1 (GND), U4.7 (GND), U4.8 (GND), U4.10 (GND), U4.14 (GND), U5.1 (GND), U5.7 (GND), U5.8 (GND), U5.10 (GND), U5.14 (GND), U6.4 (GND), ZP1.2, ZP2.2
LED 1: R1.1, U3.47 (PF3)
LED 2: R2.1, U3.46 (PF2)
LED 3: R3.1, U3.45 (XTAL32K2/PF1)
LED B: R6.1, U3.42 (PE6)
LED G: R5.1, U3.43 (PE7)
LED R: R4.1, U3.44 (XTAL32K1/PF0)
LED_DBG1: R39.2, U3.14 (PB6)
LED_DBG2: R40.2, U3.15 (PB7)
LED_IGN: R38.2, U3.28 (PD2)
LED_PWR: R36.2, U3.29 (PD3)
LED_SENS: R37.2, U3.30 (PD4)
MISO0: U3.37 (PE1), U6.2 (DO/IO_{1})
MOSI0: U3.36 (PE0), U6.5 (DI/IO_{0})
unnamed: D1.2 (A), R1.2
unnamed: D2.2 (A), R2.2
unnamed: D3.2 (A), R3.2
unnamed: D4.3 (AB), R6.2
unnamed: D4.2 (AG), R5.2
unnamed: D4.1 (AR), R4.2
unnamed: D6.1 (K), R11.1
unnamed: D7.1 (K), R12.1
unnamed: D9.1 (K), R17.1
unnamed: D10.2 (A), R19.2, U2.17 (RXD)
unnamed: D10.1 (K), R18.1
unnamed: D11.2 (A), R20.2
unnamed: D12.2 (A), R21.2
unnamed: D14.2 (A), LS1.N, Q1.3 (C)
unnamed: D15.2 (A), R36.1
unnamed: D16.2 (A), R37.1
unnamed: D17.2 (A), R38.1
unnamed: D18.2 (A), R39.1
unnamed: D19.2 (A), R40.1
unnamed: D20.1 (K), R41.2
unnamed: D21.1 (K), R42.1
unnamed: D22.1 (K), R43.2
unnamed: D23.1 (K), R44.1
unnamed: D24.2 (A), R45.1
unnamed: D25.2 (A), R46.1
unnamed: D26.2 (A), R47.1
unnamed: D27.2 (A), R48.1
unnamed: D28.1 (K), R49.2
unnamed: D29.1 (K), R50.1
unnamed: J1.A5 (CC1), R7.1
unnamed: J1.B5 (CC2), R8.1
unnamed: J2.A5 (CC1), R13.1
unnamed: J2.B5 (CC2), R14.1
unnamed: J3.1, ZP1.1, ZS1.2
unnamed: J4.1, ZP2.1, ZS2.2
unnamed: JP1.1 (A), U1.15 (~CTS)
unnamed: JP2.1 (A), U2.15 (~CTS)
unnamed: Q1.1 (B), R22.1
unnamed: R9.1, R10.2, U1.8 (VBUS)
unnamed: R12.2, U1.19 (~RXT/GPIO.3)
unnamed: R11.2, U1.20 (~TXT/GPIO.2)
unnamed: R18.2, U2.18 (TXD)
unnamed: R15.1, R16.2, U2.8 (VBUS)
unnamed: R17.2, U2.20 (~TXT/GPIO.2)
unnamed: R46.2, U4.29 (D1)
unnamed: R45.2, U4.30 (D2)
unnamed: C9.1, R32.1, U4.12 (RESET)
unnamed: U4.9 (RF), ZS1.1
unnamed: R48.2, U5.29 (D1)
unnamed: R47.2, U5.30 (D2)
unnamed: C11.1, R34.1, U5.12 (RESET)
unnamed: U5.9 (RF), ZS2.1
RST1: R32.2, R33.1, TP4.1, U3.61 (PG7)
RST2: R34.2, R35.1, TP8.1, U3.60 (PG6)
RTS1: TP5.1, U3.2 (PA4), U4.3 (RTS/SLEEP)
RTS2: TP10.1, U3.10 (PB2), U5.3 (RTS/SLEEP)
RX0: R41.1, TP13.1, U3.63 (XTALHF2/PA1), U4.5 (TXD)
RX1: J5.1, R49.1, TP15.1, U3.17 (PC1)
RX3: R43.1, TP17.1, U3.13 (PB5), U5.5 (TXD)
RX4: TP1.1, U1.18 (TXD), U3.41 (PE5)
RX_BUS: JL1.7, JL3.7
SCK0: U3.38 (PE2), U6.6 (CLK)
SCL1: JL1.2, JL3.2, R23.1, U3.19 (PC3)
SDA1: JL1.1, JL3.1, R24.1, U3.18 (PC2)
SLP: JR1.30 (26), JR3.30 (26), R26.1, U3.52 (PG0)
TX0: R27.1, R42.2, TP12.1, U3.62 (XTALHF1/PA0), U4.6 (RXD)
TX1: J5.2, R50.2, TP14.1, U3.16 (PC0)
TX3: R29.1, R44.2, TP16.1, U3.12 (PB4), U5.6 (RXD)
TX4: TP2.1, U1.17 (RXD), U3.40 (PE4)
TX_BUS: JL1.8, JL3.8
UPDI: R19.1, TP3.1, U3.51 (UPDI)
VBUS1: D5.2 (K), J1.A4_B9 (VBUS_A), J1.B4_A9 (VBUS_B), R10.1
VBUS2: D8.2 (K), J2.A4_B9 (VBUS_A), J2.B4_A9 (VBUS_B), R16.1

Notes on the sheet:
Subsystem LEDs
Pull-Up / Pull-Down
Pin Sockets / PCB Bus
Flash Storage Chip
Microcontroller
Radio module (169 MHz)
Flags
USB UPDI
Test Points
Buzzer
USB UART
Status LEDs
Debug LEDs
Mounting Holes
Power LEDs
ESD Protection
Radio module (869.5 MHz)
Cable to Umbilical Connector

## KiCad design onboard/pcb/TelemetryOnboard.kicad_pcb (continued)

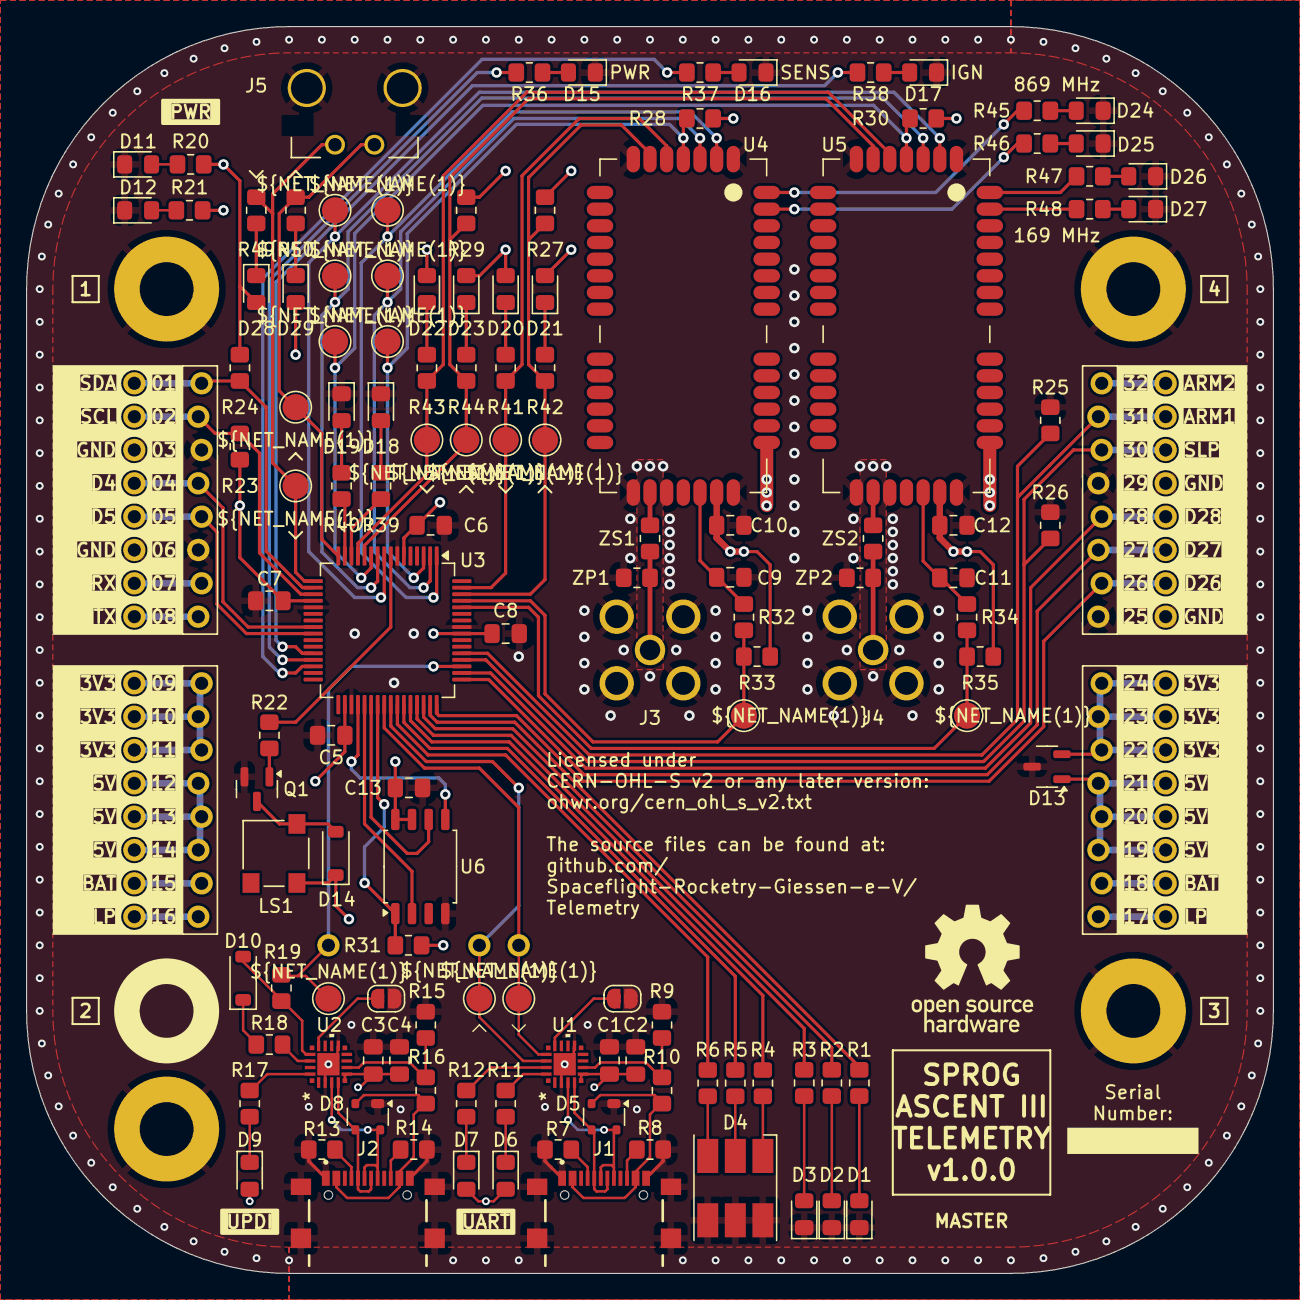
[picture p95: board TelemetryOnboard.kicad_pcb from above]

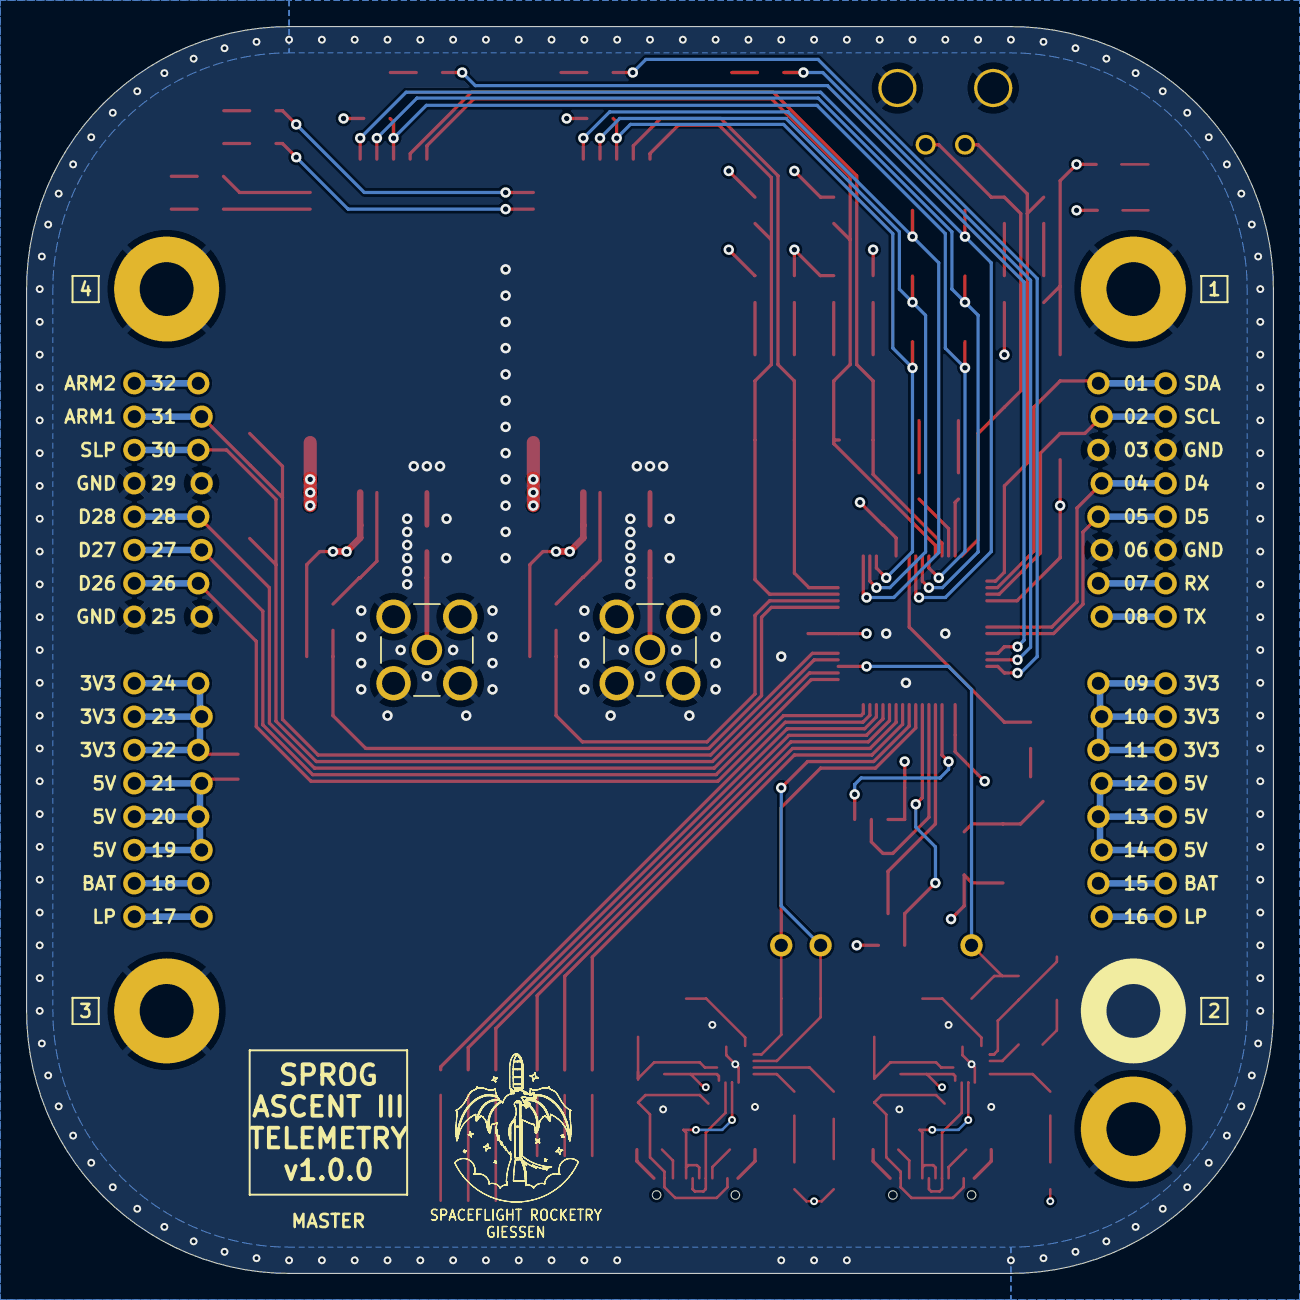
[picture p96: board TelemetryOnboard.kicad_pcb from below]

Board: 4 copper layers, 95.0 x 95.0 mm, 140 parts (2 on the bottom side), 108 nets.

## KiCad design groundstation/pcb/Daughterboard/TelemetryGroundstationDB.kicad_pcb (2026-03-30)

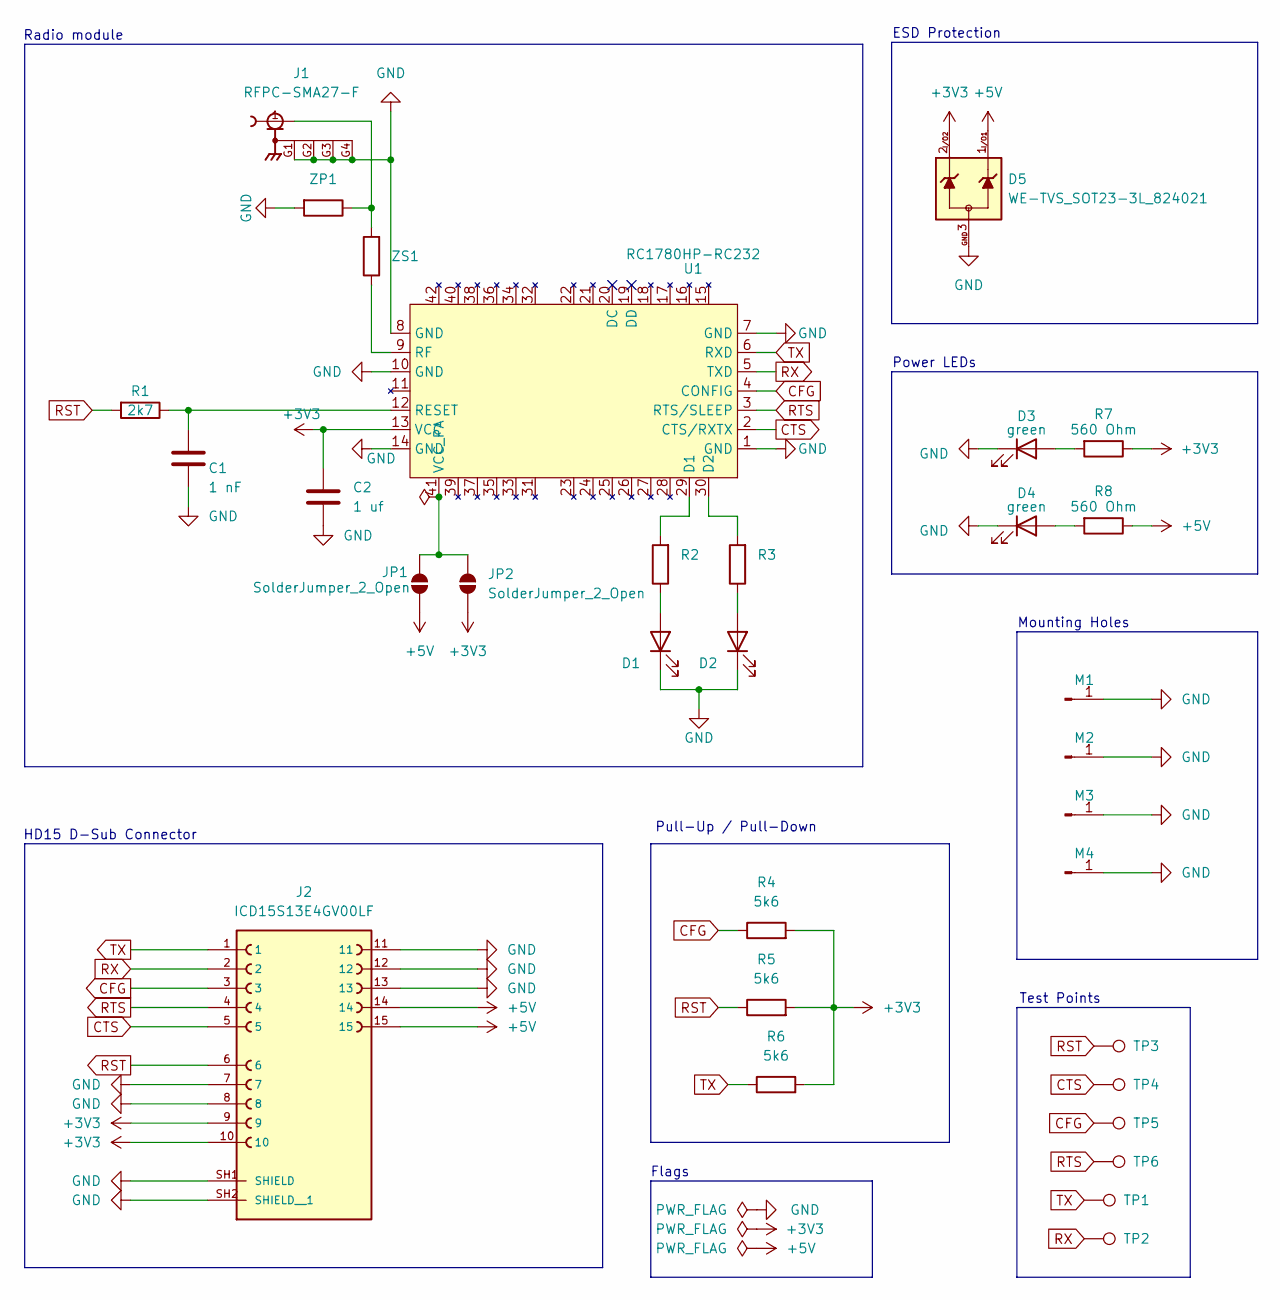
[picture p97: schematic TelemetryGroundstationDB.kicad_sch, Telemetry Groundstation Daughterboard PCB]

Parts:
C1: 1 nF; C_0805_2012Metric_Pad1.18x1.45mm_HandSolder
C2: 1 uf; C_0805_2012Metric_Pad1.18x1.45mm_HandSolder
D1, D3, D4: green; LED_0805_2012Metric_Pad1.15x1.40mm_HandSolder
D2: yellow; LED_0805_2012Metric_Pad1.15x1.40mm_HandSolder
D5: WE-TVS_SOT23-3L_824021; SOT-23-3
J1: RFPC-SMA27-F; GRADCONN_RFPC-SMA27-F; PARTREV 1.0; DigiKey_Part_Number 2073-RFPC-SMA27-F-ND
J2: ICD15S13E4GV00LF; AMPHENOL_ICD15S13E4GV00LF[1]; PARTREV G
JP1, JP2: SolderJumper_2_Open; Solder Jumper
M1, M2, M3, M4: M4 Mounting Hole
R1: 2k7; R_0805_2012Metric_Pad1.20x1.40mm_HandSolder
R2, R3: 560R; R_0805_2012Metric_Pad1.20x1.40mm_HandSolder
R4, R5, R6: 5k6; R_0805_2012Metric_Pad1.20x1.40mm_HandSolder
R7, R8: 560 Ohm; R_0805_2012Metric_Pad1.20x1.40mm_HandSolder
TP1, TP2, TP3, TP4, TP5, TP6: TestPoint; Test Point
U1: RC1780HP-RC232; Radiocrafts RC1780HP-RC232
ZP1: R_0805_2012Metric_Pad1.20x1.40mm_HandSolder
ZS1: R_0805_2012Metric_Pad1.20x1.40mm_HandSolder

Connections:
+3V3: C2.1, D5.2, J2.9, J2.10, JP2.1 (A), R4.2, R5.2, R6.2, R7.1, U1.13 (VCC)
+5V: D5.1, J2.14, J2.15, JP1.1 (A), R8.1
CFG: J2.3, R4.1, TP5.1, U1.4 (CONFIG)
CTS: J2.5, TP4.1, U1.2 (CTS/RXTX)
GND: C1.2, C2.2, D1.1 (K), D2.1 (K), D3.1 (K), D4.1 (K), D5.3, J1.G1, J1.G2, J1.G3, J1.G4, J2.7, J2.8, J2.11, J2.12, J2.13, J2.SH1 (SHIELD), J2.SH2 (SHIELD__1), M1.1, M2.1, M3.1, M4.1, U1.1 (GND), U1.7 (GND), U1.8 (GND), U1.10 (GND), U1.14 (GND), ZP1.2
unnamed: D1.2 (A), R2.1
unnamed: D2.2 (A), R3.1
unnamed: D3.2 (A), R7.2
unnamed: D4.2 (A), R8.2
unnamed: J1.1, ZP1.1, ZS1.2
unnamed: JP1.2 (B), JP2.2 (B), U1.41 (VCC_PA)
unnamed: R2.2, U1.29 (D1)
unnamed: R3.2, U1.30 (D2)
unnamed: C1.1, R1.1, U1.12 (RESET)
unnamed: U1.9 (RF), ZS1.1
RST: J2.6, R1.2, R5.1, TP3.1
RTS: J2.4, TP6.1, U1.3 (RTS/SLEEP)
RX: J2.2, TP2.1, U1.5 (TXD)
TX: J2.1, R6.1, TP1.1, U1.6 (RXD)

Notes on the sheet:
Pull-Up / Pull-Down
Radio module
Flags
Test Points
HD15 D-Sub Connector
Mounting Holes
Power LEDs
ESD Protection

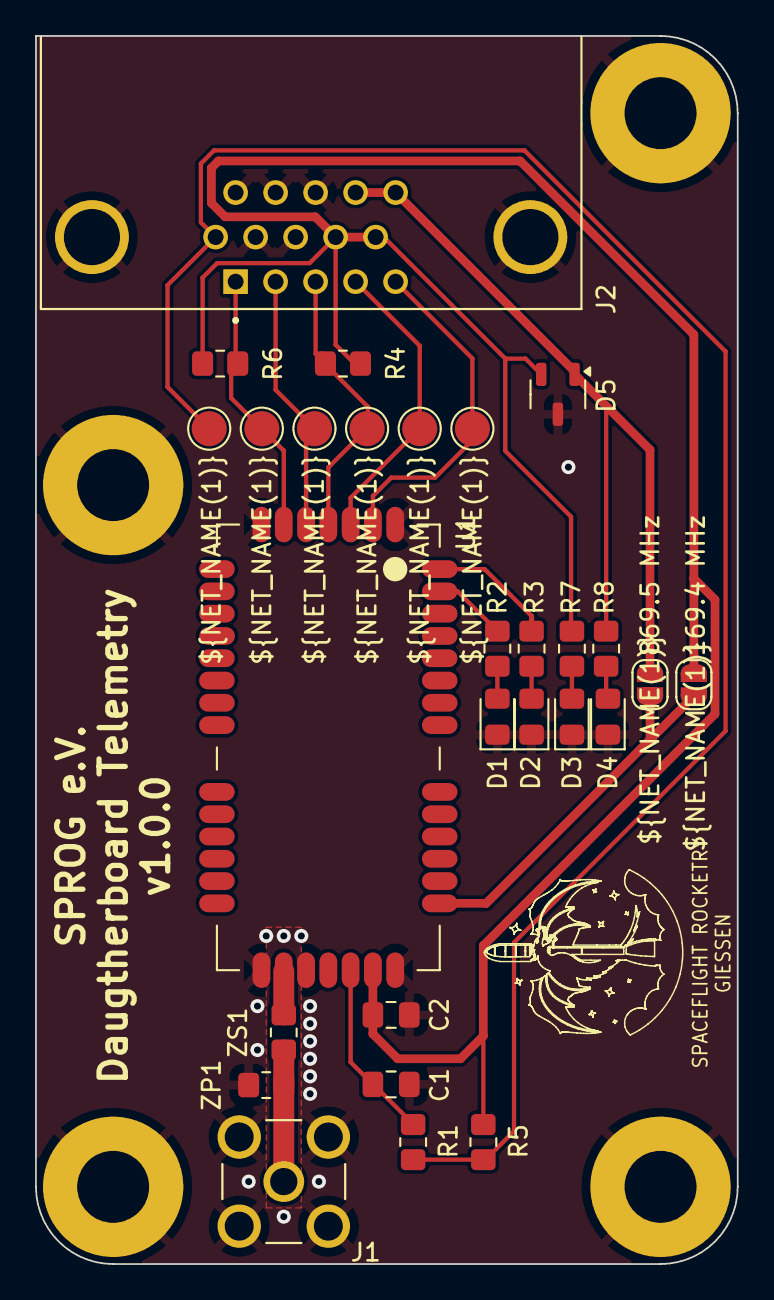
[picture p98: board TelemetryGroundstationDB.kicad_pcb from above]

Board: 2 copper layers, 40.0 x 70.0 mm, 32 parts (0 on the bottom side), 19 nets.

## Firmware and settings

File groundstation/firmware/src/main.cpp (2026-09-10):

/*
    groundstation - main.cpp of the groundstation for the ASCENT III telemetry system.
    Spaceflight Rocketry Giessen e.V.
    Published under the CERN OHL-S v2 license at https://github.com/Spaceflight-Rocketry-Giessen-e-V/Telemetry.
*/

#include "header.h"
#include "utility.h"

// LED Pins Initialization

ledStruct pinLed;

// Button Pins Initialization

buttonStruct pinButton;

// Pin Declarations

uint8_t pinControlBox1 = PIN_PE7;
uint8_t pinControlBox2 = PIN_PE6;

// UART Declarations

HardwareSerial *SerialUSB1 = &Serial5;
HardwareSerial *SerialUSB2 = &Serial2;

uint8_t pinTX_USB1 = PIN_PG0;
uint8_t pinRX_USB1 = PIN_PG1;
uint8_t pinTX_USB2 = PIN_PF0;
uint8_t pinRX_USB2 = PIN_PF1;

// Initialize Radio Modules

// First D-Sub
RC17xxHP_RC232 rc1780hp(&Serial4, PIN_PE0, PIN_PE1, 19200, PIN_PE4, PIN_PE5, PIN_PE2, PIN_PE3);
// Second D-Sub
RC17xxHP_RC232 rc1701hp(&Serial1, PIN_PC0, PIN_PC1, 19200, PIN_PC4, PIN_PC5, PIN_PC2, PIN_PC3);

// Packet Declarations

Packet commandPacket;
Packet framePacket;
Packet flightDataPacket;
Packet telemetryDataPacket;

// 

dataStruct dataVars;

uint8_t packetBuffer[32];
uint8_t packetBufferIndex = 0;

void setup()
{
  pinLed.R = PIN_PG5;
  pinLed.G = PIN_PG4;
  pinLed.B = PIN_PG3;
  pinLed.D1 = PIN_PA0;
  pinLed.D2 = PIN_PG7;
  pinLed.D3 = PIN_PG6;
  pinLed.rssi_1 = PIN_PD7;
  pinLed.rssi_2 = PIN_PD6;
  pinLed.rssi_3 = PIN_PD5;
  pinLed.rssi_4 = PIN_PD4;
  pinLed.rssi_5 = PIN_PD3;
  pinLed.rssi_6 = PIN_PD2;
  pinLed.rssi_7 = PIN_PD1;
  pinLed.rssi_8 = PIN_PD0;

  pinLed.pinMode();

  pinButton.sw1 = PIN_PG2;
  pinButton.sw2 = PIN_PF6;
  pinButton.sw3 = PIN_PF5;
  pinButton.sw4 = PIN_PF4;
  pinButton.sw5 = PIN_PF3;
  pinButton.sw6 = PIN_PF2;

  pinButton.pinMode();

  pinMode(pinControlBox1, INPUT);
  pinMode(pinControlBox2, INPUT);

  ledUpdate(SETUPBEGIN, &pinLed); // R On

  // UART Declarations

  SerialUSB1->pins(pinTX_USB1, pinRX_USB1);
  SerialUSB2->pins(pinTX_USB2, pinRX_USB2);

  SerialUSB1->begin(115200);
  SerialUSB2->begin(115200);

  // Initialize I2C (Display)

  // Wire.pins(PIN_PC6, PIN_PC7);
  // Wire.begin();

  // Initialize Radio Modules

  radioModulesSetup(&rc1780hp, &rc1701hp, &pinLed);

  ledUpdate(SETUPRADIOMODULS, &pinLed); // B On

  // Packet Components Initializations

  commandPacket.addComponent(new parity_Component());
  commandPacket.addComponent(new char_Component(&dataVars.command));

  framePacket.addComponent(new cobs_Component(0xEE, 4));
  framePacket.addComponent(new parity_Component());
  framePacket.addComponent(new uint8_t_Component(&dataVars.packetIdentifier, 1, 0, 1));
  framePacket.addComponent(new empty_Component(18));
  framePacket.addComponent(new empty_Component(32));
  framePacket.addComponent(new empty_Component(32));
  framePacket.addComponent(new const_Component(0xEE, 8, 255));
  framePacket.addComponent(new float_Component(&dataVars.rssi, 8, -127.5, 0, 255));

  flightDataPacket.addComponent(new empty_Component(6));
  flightDataPacket.addComponent(new float_Component(&dataVars.acceleration, 10, -17, 17.1));
  flightDataPacket.addComponent(new float_Component(&dataVars.heightPressure, 15, 0, 6553.4));
  flightDataPacket.addComponent(new uint8_t_Component(&dataVars.flightEvents, 5, 0, 31));
  flightDataPacket.addComponent(new float_Component(&dataVars.latitude, 26, -90, 90));
  flightDataPacket.addComponent(new float_Component(&dataVars.longitude, 26, -180, 180));
  flightDataPacket.addComponent(new empty_Component(16));

  telemetryDataPacket.addComponent(new empty_Component(6));
  telemetryDataPacket.addComponent(new empty_Component(2));
  telemetryDataPacket.addComponent(new uint8_t_Component(&dataVars.stateTelemetry, 2, 0, 3));
  telemetryDataPacket.addComponent(new uint8_t_Component(&dataVars.stateControl, 2, 0, 3));
  telemetryDataPacket.addComponent(new uint8_t_Component(&dataVars.statePower, 2, 0, 3));
  telemetryDataPacket.addComponent(new uint8_t_Component(&dataVars.stateSens, 2, 0, 3));
  telemetryDataPacket.addComponent(new empty_Component(1));
  telemetryDataPacket.addComponent(new float_Component(&dataVars.heightGNSS, 15, 0, 6553.4));
  telemetryDataPacket.addComponent(new uint8_t_Component(&dataVars.satCountGNSS, 4, 0, 15));
  telemetryDataPacket.addComponent(new float_Component(&dataVars.hdopGNSS, 4, 0, 7.5));
  telemetryDataPacket.addComponent(new uint8_t_Component(&dataVars.temperatureElectronics, 4, 0, 150));
  telemetryDataPacket.addComponent(new uint8_t_Component(&dataVars.temperatureBattery, 4, 0, 150));
  telemetryDataPacket.addComponent(new uint8_t_Component(&dataVars.stateCapacitors, 4, 0, 15));
  telemetryDataPacket.addComponent(new uint8_t_Component(&dataVars.continuityPyros, 2, 0, 3));
  telemetryDataPacket.addComponent(new uint8_t_Component(&dataVars.pressureDecoupler, 1, 0, 1));
  telemetryDataPacket.addComponent(new uint8_t_Component(&dataVars.ldrDecoupler, 1, 0, 1));
  telemetryDataPacket.addComponent(new empty_Component(2));
  telemetryDataPacket.addComponent(new float_Component(&dataVars.voltageBattery, 6, 5, 8.15));
  telemetryDataPacket.addComponent(new float_Component(&dataVars.currentBattery, 3, 0, 1.75));
  telemetryDataPacket.addComponent(new float_Component(&dataVars.currentUmbilical, 3, 0, 1.75));
  telemetryDataPacket.addComponent(new uint8_t_Component(&dataVars.stateUmbilical, 1, 0, 1));
  telemetryDataPacket.addComponent(new uint8_t_Component(&dataVars.lowPowerMode, 1, 0, 1));
  telemetryDataPacket.addComponent(new float_Component(&dataVars.voltageBatteryCOTS, 5, 5, 11.2));
  telemetryDataPacket.addComponent(new empty_Component(11));
  telemetryDataPacket.addComponent(new empty_Component(16));

  // Setup Complete

  ledUpdate(SETUPEND, &pinLed); // G On
}

void loop()
{
  // Check both USBs for commands
  dataVars.command = commandReceive(SerialUSB1);
  commandExecute(&rc1701hp, dataVars.command, &commandPacket);
  dataVars.command = commandReceive(SerialUSB2);
  commandExecute(&rc1701hp, dataVars.command, &commandPacket);

  buttonCheck(pinButton);
  controlBoxCheck(pinControlBox1, pinControlBox2);

  if (packetReceive(&rc1780hp, packetBuffer, &packetBufferIndex, &dataVars, &framePacket, &flightDataPacket, &telemetryDataPacket) == 0)
  {
    dataSendUsb(SerialUSB1, &dataVars);
    dataSendUsb(SerialUSB2, &dataVars);

    displayUpdate(0x00, &dataVars);

    ledRssiUpdate(dataVars.rssi, &pinLed);
  }
}

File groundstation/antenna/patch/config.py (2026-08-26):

# -*- coding: utf-8 -*-
"""
Simulation constants for the RHCP patch antenna.

All physical parameters and derived mesh/sim settings live here.
No switches, no side effects — safe to import from any module.
"""

import numpy as np
from openEMS.physical_constants import C0, EPS0

# ── Antenna target ────────────────────────────────────────────────
f_target = 869.525e6  # Hz — operating frequency (EU 868 g3 high-power sub-band centre)
fc       = 250e6      # Hz — Gaussian excitation half-bandwidth / post-proc sweep half-width
feed_R   = 50         # Ω  — lumped port impedance

# ── Substrate: Nan Ya NP-140F, 2-layer 1.6 mm (datasheet-specified) ──
# Switched BACK to NP-140F from generic stock FR-4 because the fab guarantees the
# laminate at EQUAL cost: we design to its DATASHEET εr (4.0–4.2 @ 1 GHz, ±0.1) instead
# of stock FR-4's unspecified ~4.2–4.6 spread (the real stock part, KingBoard KB-6164,
# measures ~4.6 / 0.0155 @ 1 GHz). Known + tighter εr means the simulated resonance lands
# on the bench (~±10 MHz batch scatter vs ~±20 MHz on KB-6164) and the patch sees a
# lower-Q, wider-band dielectric. The ~0.3–0.5 dB loss edge is irrelevant (22–30 dB link
# margin) — predictability is the reason. εr nudged to 4.15 (rises slightly below 1 GHz,
# toward 869.52 MHz); tanδ ~0.014. See docs/NP-140F-Datasheets.pdf.
substrate_material  = 'NP-140F'
substrate_epsR      = 4.15   # relative permittivity @ ~870 MHz (NP-140F datasheet 4.0–4.2 @ 1 GHz)
substrate_tanD      = 0.014  # loss tangent @ ~870 MHz (NP-140F datasheet 0.012–0.014 @ 1 GHz)
substrate_thickness = 1.6    # mm
substrate_cells     = 4      # FDTD cells through substrate thickness

# ── FDTD domain ───────────────────────────────────────────────────
SimBox   = np.array([600, 600, 600])  # simulation domain [mm]. Sized so the centred
                                      # board clears ≳λ/4 to the inner PML_8 boundary on
                                      # every face — PML_8 consumes ~8·mesh_res (≈107 mm)
                                      # inside each face.
NrTS_opt   = 150000  # time steps per optimisation run. Set EQUAL to NrTS_final so the
                     # optimiser judges AR at the same fidelity as the confirm stage: the razor
                     # AR/beamwidth does not survive a coarse→fine change, so a cheaper opt run
                     # selects on an optimistic AR that collapses at full fidelity.
NrTS_final = 350000  # time steps for the final high-fidelity run. the
                     # razor CP AR null is time-step-limited at 150k (a direct 150k vs 250k
                     # re-run of the locked W=82.5/trunc=8.25 design moved the AR null depth
                     # 0.41->1.03 dB and the AR<=3 freq band 7.9->6.6 MHz — the 150k numbers
                     # were optimistic). 350k is the convergence top-rung to confirm 250k is
                     # settled and to write a convergence-proven results.json (see tests/
                     # tool_trunc_bw_sweep.py + the convergence ladder in docs/research.md §3).
NrTS_screen = 150000  # SCREEN fidelity for the W×truncation grid. Equal to
                     # NrTS_opt: the screen must centre the AR NULL (optimizer._screen_cost on
                     # f_ar_null), and the razor AR null does NOT converge at 60k — a 60k run read
                     # AR 8.8 dB where the 150k truth is 0.4 dB, so a cheap screen mis-ranked the
                     # null-centred design (the whole single-feed re-tune traced to that). At full
                     # fidelity the null frequency is reliable; CONFIRM then re-applies the full
                     # coverage cost (incl. AR depth/beamwidth at f_target) to pick the winner.

# Parallel FDTD workers (within-phase). 0 = use os.cpu_count().
# Each worker spawns one openEMS subprocess; OMP_NUM_THREADS is set to 1
# per worker so openEMS doesn't itself try to claim all cores.
# Lower this if RAM is tight (~200–500 MB per concurrent sim).
num_workers = 0

# Hard ceiling on concurrent workers, applied on top of num_workers/cpu_count.
# Caps peak RAM/temp-disk and keeps the wall-clock estimate honest. Both the optimiser pool
# and the ETA derive from this via optimizer.resolve_workers(), so they can never disagree.
#
# SET TO 3: at the full NrTS_screen = NrTS_opt = 150k the openEMS NF2FF recording per
# sim is large, and 9 concurrent 150k sims returned EMPTY NF2FF (Prad/Dmax≈0 with a still-valid
# S11) — a RAM/temp-disk overrun — whereas 3-concurrent×150k and 9-concurrent×60k both ran clean.
# 3 keeps every phase inside the proven-safe regime; on a ~20-thread host _run_batch then gives
# each sim cores//3 ≈ 6 FDTD threads (faster per sim), so the 9-sim grid runs as 3 quick waves at
# ~the same wall-clock as one slow 9-wide wave. The worker ALSO guards against empty NF2FF (returns
# a failure so a tripped sim is excluded, not silently selected). Raise only on a host with RAM/
# scratch verified at 150k.
MAX_WORKERS = 3
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

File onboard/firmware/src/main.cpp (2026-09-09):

/*
    onboard - main.cpp of the board computer for the ASCENT III telemetry system.
    Spaceflight Rocketry Giessen e.V.
    Published under the CERN OHL-S v2 license at https://github.com/Spaceflight-Rocketry-Giessen-e-V/Telemetry.
*/

#include "header.h"
#include "utility.h"

// LED Pins Initialization

ledStruct pinLed;

// Pin Declarations

uint8_t pinSLP = PIN_PG0;
uint8_t pinARM1 = PIN_PG1;
uint8_t pinD26 = PIN_PF4;
uint8_t pinD27 = PIN_PF5;
uint8_t pinD28 = PIN_PF6;
uint8_t pinD4 = PIN_PC6;
uint8_t pinD5 = PIN_PC7;
uint8_t pinBuzzer = PIN_PB0;

// UART Declarations

HardwareSerial *SerialUSB = &Serial4;
HardwareSerial *SerialUmbilical = &Serial1;

uint8_t pinTX_USB = PIN_PE4;
uint8_t pinRX_USB = PIN_PE5;
uint8_t pinTX_Umbilical = PIN_PC0;
uint8_t pinRX_Umbilical = PIN_PC1;

// Initialize Radio Modules

RC17xxHP_RC232 rc1780hp(&Serial0, PIN_PA0, PIN_PA1, 19200, PIN_PA5, PIN_PG7, PIN_PA3, PIN_PA4);
RC17xxHP_RC232 rc1701hp(&Serial3, PIN_PB4, PIN_PB5, 19200, PIN_PB3, PIN_PG6, PIN_PB1, PIN_PB2);
dataStruct dataVars;

// Data Arrays Preparations

const uint8_t uint8CountPower = 3;
uint8_t *uint8ListPower[uint8CountPower] = {&dataVars.statePower, &dataVars.stateUmbilical, &dataVars.temperatureBattery};
const uint8_t floatCountPower = 4;
float *floatListPower[floatCountPower] = {&dataVars.currentUmbilical, &dataVars.currentBattery, &dataVars.voltageBattery, &dataVars.voltageBatteryCOTS};

const uint8_t uint8CountSens = 3;
uint8_t *uint8ListSens[uint8CountSens] = {&dataVars.stateSens, &dataVars.satCountGNSS, &dataVars.temperatureElectronics};
const uint8_t floatCountSens = 6;
float *floatListSens[floatCountSens] = {&dataVars.latitude, &dataVars.longitude, &dataVars.heightPressure, &dataVars.acceleration, &dataVars.heightGNSS, &dataVars.hdopGNSS};

const uint8_t uint8CountControl = 6;
uint8_t *uint8ListControl[uint8CountControl] = {&dataVars.stateControl, &dataVars.flightEvents, &dataVars.stateCapacitors, &dataVars.pressureDecoupler, &dataVars.ldrDecoupler, &dataVars.continuityPyros};
const uint8_t floatCountControl = 0;
float *floatListControl[floatCountControl] = {};

// Subsystems Initialization

Subsystem subsystemPower(0x50, &pinLed.Power, &dataVars.statePower, uint8ListPower, uint8CountPower, floatListPower, floatCountPower);
Subsystem subsystemSens(0x20, &pinLed.Sens, &dataVars.stateSens, uint8ListSens, uint8CountSens, floatListSens, floatCountSens);
Subsystem subsystemControl(0x40, &pinLed.Control, &dataVars.stateControl, uint8ListControl, uint8CountControl, floatListControl, floatCountControl);

const uint8_t subsystemsCount = 3;
Subsystem *subsystemList[subsystemsCount] = {&subsystemSens, &subsystemPower, &subsystemControl};

// Packet Declarations

Packet commandPacket;
Packet flightDataPacket;
Packet telemetryDataPacket;

// Loop Variables Declaration

const uint8_t loopFrequency = 10;            // in Hz       10 Hz = 100 ms interval
const uint8_t timeBetweenStandbyPackets = 5; // in seconds. In standby, data packets aren't send every loop

uint8_t flightMode = 0;
uint32_t loopCount = 0;
uint32_t loopStartTime = 0;

void setup()
{
  pinLed.R = PIN_PF0;
  pinLed.G = PIN_PE7;
  pinLed.B = PIN_PE6;
  pinLed.D1 = PIN_PF3;
  pinLed.D2 = PIN_PF2;
  pinLed.D3 = PIN_PF1;
  pinLed.Debug1 = PIN_PB6;
  pinLed.Debug2 = PIN_PB7;
  pinLed.Power = PIN_PD3;
  pinLed.Sens = PIN_PD4;
  pinLed.Control = PIN_PD2;

  pinLed.lowPowerMode = new uint8_t(0);

  pinLed.pinMode();

  ledUpdate(SETUPBEGIN, &pinLed); // R On

  // Pin Initialisations

  pinMode(pinSLP, OUTPUT);
  pinMode(pinARM1, OUTPUT);
  pinMode(pinBuzzer, OUTPUT);

  digitalWrite(pinSLP, LOW);
  digitalWrite(pinARM1, LOW);

  // UART Declarations

  SerialUSB->pins(pinTX_USB, pinRX_USB);
  SerialUmbilical->pins(pinTX_Umbilical, pinRX_Umbilical);

  SerialUSB->begin(115200);
  SerialUmbilical->begin(115200);

  // Initialize I2C

  Wire.pins(PIN_PC2, PIN_PC3);
  Wire.begin();

  // Initialize Radio Modules

  radioModulesSetup(&rc1780hp, &rc1701hp, &pinLed, pinBuzzer);

  ledUpdate(SETUPRADIOMODULS, &pinLed); // B On

  // Packet Components Initializations

  commandPacket.addComponent(new parity_Component());
  commandPacket.addComponent(new char_Component(&dataVars.command));

  flightDataPacket.addComponent(new cobs_Component(0xEE, 4));
  flightDataPacket.addComponent(new parity_Component());
  flightDataPacket.addComponent(new const_Component(0, 1));
  flightDataPacket.addComponent(new float_Component(&dataVars.acceleration, 10, -17, 17.1));
  flightDataPacket.addComponent(new float_Component(&dataVars.heightPressure, 15, 0, 6553.4));
  flightDataPacket.addComponent(new uint8_t_Component(&dataVars.flightEvents, 5, 0, 31));
  flightDataPacket.addComponent(new float_Component(&dataVars.latitude, 26, -90, 90));
  flightDataPacket.addComponent(new float_Component(&dataVars.longitude, 26, -180, 180));
  flightDataPacket.addComponent(new const_Component(0xEE, 8, 255));
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

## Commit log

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2025-08-06 reworked repos structure
    [CONSMA001-SMD-G-T.step, PLCC6_CLP6C-FKB_CRW.step, RC1191-TM.STEP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]
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2025-08-31 fixed silkscreen
    [TelemetryOnboard.kicad_pcb]
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2025-08-31 pcb renderings and production files
    new 3d models of pcb and new high quality renderings as well as new production files
    [Onboard_PCB.f3d, Onboard_PCB.step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]
2025-09-01 PCB ready for production v0.0.1
    fixed remaining issue with silkscreen, recreated production files and renderings
    [Onboard_PCB.f3d, Onboard_PCB.step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]
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2025-10-19 add better simulation with csv IO
    update simulation with more realistic values and add io support for csv flight data files
    [flight_data_2025-10-19_15-06-35.csv]
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2025-11-10 update to onboard firmware
    fix to i2c comm bugs and more
    [main.cpp]
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2025-11-26 Extract Simulation to its own project and UI
    Extract Simulation and CSV creation from Meerkat to its own subproject
    Remove Simulation from Meerkat
    [flight_data_2025-10-19_15-06-35.csv]
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2025-11-26 Move Flight Simulator to a new repo (Flight-Simulations)
    Move Flight Simulator to a new repo:
    https://github.com/Spaceflight-Rocketry-Giessen-e-V/Flight-Simulations
    [flight_data_2025-11-26_20-22-01.csv]
2025-11-26 Revert "Move Flight Simulator to a new repo (Flight-Simulations)"
    This reverts commit 58ceaefa8945c6d6937643d7d5f0cca2419e6927.
    [flight_data_2025-11-26_20-22-01.csv]
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2025-12-10 Refactor GUI architecture and add telemetry receiver
    Major refactor of the groundstation GUI: migrated UI logic to UIManager, removed simulation.py, and reorganized UI components into dedicated windows. Added Arduino telemetry simulation sketch and a n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
    [telemetry_log.csv]
2025-12-10 Ignore telemetry log files and remove tracked logs
    Added telemetry log files and Python cache files to .gitignore to prevent them from being tracked. Deleted existing telemetry_log.csv and telemetry_log.txt from the repository.
    [telemetry_log.csv]
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2025-12-10 Fix arrow direction in accelerometer window
    Swapped the head and tail points in the draw_arrow call to ensure the arrow points in the correct direction in the accelerometer window.
    [accelerometer_window.py]
2025-12-11 Update UI layouts and telemetry parsing
    Adjusted UI layout in UIManager for better grouping and sizing of elements. Updated battery voltage thresholds in BatteryWindow. Modified flight event list in FlightEventMonitor to new event descriptions. Improved telemetry parsing for negative acceleration values and changed serial decoding error handling and console logging defaults.
    [battery_window.py, flight_events_window.py]
2025-12-11 add parachute deployment capability and parity check
    fixes #10
    [main.cpp]
2025-12-11 add parity check
    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
    [main.cpp]
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2026-02-02 first version new schematic
    added symbols, footprints, 3dmodels, added new pcb base layout, added first schematic elements
    [Buzzer CMT-0525-75-SMT-TR.step, RGB LED PLCC6_CLP6C-FKB_CRW.step, Radiocrafts RC1780HP-RC232.STEP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]
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2026-02-18 Add COM controller, commands UI, and sim v2
    Introduce a new telemetry serial controller and UI command window, plus a v2 Arduino simulation sketch and dependency updates.
    Added groundstation/gui/telemetry/com_controller.py which replaces the older telemetry_receiver, providing parsing, CSV/TXT logging, UI callbacks, thread-based listening, and a send_command API with mapped command names.
    Added CommandsWindow and integrated it into the UI (ui_manager) and com_monitor_controller now uses the new TelemetryReceiver (start/stop, set_ui_callback) and exposes controller for the commands UI.
    Updated ComMonitor table formatting and improved UI layout/titles.
    Added a richer arduino_simulation_sketch_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
    [com_controller.py, com_monitor.py, com_monitor_controller.py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]
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2026-03-01 update coplanar waveguid calculation
    fixes #28. Added separate caluclations for groundstation and onboard and updates the values
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2026-03-05 rework schematic, add D and Q value
    [TelemetryOnboard.kicad_pcb, TelemetryOnboard.kicad_sch]
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2026-03-12 Arduino sim, fonts & settings; telemetry refactor
    Add an Arduino flight simulation sketch and include Noto Sans variable fonts with OFL and README. Introduce persistent UI settings (settings.json) and a settings_manager to load/save defaults; add several new UI windows (settings, connection, time, acceleration) and mark accelerometer_window as deprecated. Refactor telemetry/com_controller.py into a robust TelemetryReceiver: thread-based serial listener, structured parsing, timestamped per-session logs (CSV/text), improved logging/error handling, and a clearer command API. Also update requirements (add tzdata), ignore logs in .gitignore, and remove the backlog file. Closes #15
    [acceleration_window.py, altitude_window.py, arduino_simulation_sketch_v3.ino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]
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2026-03-19 improve manual structure and add cp2102n manual
    include manual for programming the leds connected to the cp2102n usb-to-uart bridge. fixes #25
2026-03-20 fix file name typos
    [TelemetryGroundstationDB_BOM.csv]
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2026-03-21 inluce kicad custom libraries manual
    fixes #19
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2026-03-22 improve component 3d models
    also update pcb 3d models and renderings. fixes #35
    [CT3151-2.step, ICD15S13E4GV00LF.step, LD09S33E4GV00LF.step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]
2026-03-28 update code for new groundstation pcb Fixes #33
    [main.cpp]
2026-03-30 update onboard firmware (new pcb)
    update pin assignments fixes #36
    [main.cpp]
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2026-03-31 Remove FlightData simulation files
    Delete the FlightData simulation module and its example data
    [flight_data_2025-11-26_20-22-01.csv]
2026-04-11 Add helix antenna build manual and images
    Add a comprehensive Helix Antenna Build Manual (docs/antenna_assembly_manual.md) covering overview, bill of materials, step-by-step build phases, and a build checklist with references to 3D print files.
    Include a full set of supporting photos files under docs/images/antenna_assembly to document pacifier prep, rod prep, epoxy application, coil winding, coil insertion, and final assembly.
    Fixes #16
2026-04-11 Organize media assets and update README paths
    Move media assets into structured directories (docs/, onboard/pcb/, groundstation/pcb/) and rename 3D model and image files accordingly.
    Update README.md to reference the new image locations and remove an unused image (media/images/meerkat_demo_1.png).
    These changes reorganize repository media for clearer project structure and maintain correct relative links in documentation.
    Fixes #41
    Causes #44
    [Onboard_PCB.f3d, Onboard_PCB.step, Onboard_PCB_NoSilkscreen.step]
2026-04-11 Update antenna assembly manual wording & links
    Revise docs/antenna_assembly_manual.md:
    Minor Fixes
    Restructure the BOM table and add direct links
    Clean up repeated/duplicated instructions.
    Small editorial fixes: clarify epoxy safety (add eye protection), streamline winding/coil wording, note acceptable coil irregularity, refine checklist item text (clamps, Cone Top/Bottom, Rope Fixture), fix drill template reference, and remove minor dead text/duplication.
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2026-04-11 remove old 3d models
    3d models in question were outdated anyways :) fixes #44
    [Onboard_PCB.f3d, Onboard_PCB.step, Onboard_PCB_NoSilkscreen.step]
2026-04-11 add drilling template
    fixes #39
2026-04-12 update helix antenna assembly manual
    rework text, downsize images and more
2026-04-16 Add run.bat; plotting controls & UI fixes
    Add a Windows run.bat to create/activate venv, install requirements and launch main.py.
    Update UI: remove emoji from Settings tab label and fix swapped altitude update calls in ui_manager (GNSS vs pressure).
    Enhance AccelerationWindow and AltitudeWindow with Stop/Resume and Reset Plot buttons, implement resume/reset logic, adjust layout and tags, and remove per-sample delta/median tracking from altitude stats.
    Fix MapViewWindow GPS validity check to use the local lat/lon parameters instead of self members.
    [acceleration_window.py, altitude_window.py, map_view_window.py]
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2026-04-26 add Digikey purchase links for Daughter- and Motherboard
    fixes #30
    [TelemetryGroundstationDB.kicad_sch, TelemetryGroundstationDB_BOM.csv, TelemetryGroundstationMB.kicad_pcb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]
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2026-05-07 fix 3D Models and rearrange wires. Fixes #46
    [TelemetryGroundstationMB.kicad_pcb, TelemetryGroundstationMB.kicad_sch, TelemetryOnboard.kicad_pcb]
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2026-05-09 Add antennas simulation to user_manual.md
    fixes #21
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2026-05-27 create rough firmware outline
    fixes #49 fixes #50 Co-Authored-By: BenjaminBBBBBB <benjamin.bauersfeld@t-online> Co-Authored-By: Abakus2k <mail@pascalschlag.de> Co-Authored-By: Niklas-2911 <niklas_ow@proton.me>
    [main.cpp]
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2026-05-31 add function definitions to header files and main
    fixes #47 fixes #48
    [main.cpp]
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2026-06-02 Restructure antenna folder: split into helical/ and add patch antenna
    groundstation/antenna/ now holds one subfolder per antenna design:
    - helical/: the existing 869 MHz helical antenna (moved unchanged)
    - patch/: new RHCP patch antenna simulation source imported from the
    standalone PatchAntennaSimulation project (source only: config.py,
    run.py, requirements.txt, src/*.py), with a scoped .gitignore for the
    regenerable openEMS/FDTD run output.
    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
    [Antenna Assembly.f3z, Antenna Assembly.step, Cone Bottom.step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]
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2026-06-03 Refactor patch antenna optimizer: share metrics, remove dead code, fix logic
    Structural cleanup (no change to simulation physics or exported PCB geometry):
    - Extract shared S11 / axial-ratio / centroid / eval-grid / failure-result
    helpers into new src/metrics.py, used by both the optimizer worker and the
    post-processor (removes copy-pasted numeric logic across three files).
    - Delete the dead _run_single method and its now-unused shutil/tempfile imports.
    - Drop the never-enabled _dbg tracer from build_sim.
    - Single-source the phase schedule (PHASES table) feeding n_opt, the ETA and the
    banner label; add _mk_kw helper; add src/__init__.py package marker.
    - Functionize run.py's 227-line _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
    [config.py, run.py]
2026-06-03 Docs: fix broken helical-antenna links and restore reverted wording
    - README.md: repoint the Assembly Manual link to the renamed
    helical_antenna_assembly_manual.md (the old helix_ path was a dead link).
    - design_overview.md: restore "Helical" wording lost in the merge -- the TOC
    entry and its anchor, the intro sentence, and the section heading.
    - helix_antenna_design_guide.ipynb: fix 3 broken image links
    (images/helix_plot_*.png -> images/helical_plot_*.png).
    Physical-coil-shape mentions, external URLs, and the (un-renamed) design-guide
    notebook name are intentionally left as "helix".
2026-06-03 Patch antenna: fail fast on missing openEMS bindings + setup docs
    The CSXCAD/openEMS Python bindings are not on PyPI or conda, so a fresh
    clone dies with a deep "ModuleNotFoundError: No module named 'CSXCAD'"
    traceback. Add a guardrail tier so launches fail with clear guidance:
    - run.py: preflight_check() called first in main(). Self-heals the
    Windows DLL path (auto-sets OPENEMS_INSTALL_PATH to a standard openEMS
    install if unset), then verifies the bindings import; on failure prints
    an actionable message (install steps, matching-Python note) and exits 1
    instead of a stack trace. Imports only the two bindings so bare
    `import run` stays lightweight, per the module-scope design.
    - .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
    [run.py]
2026-06-03 @ Patch antenna optimizer: parallelization fixes and grid tuning
    - Reuse one ProcessPoolExecutor across all phases instead of rebuilding it
    per phase, avoiding 7x worker respawn + openEMS re-import on Windows spawn.
    - Control openEMS threads via Run(numThreads=...): workers get their dynamic
    share of cores (immune to inherited OMP_NUM_THREADS, which setdefault left
    unenforced), the final/single sim claims all cores, and under-filled waves
    hand idle cores to the running sims.
    - Add a per-phase as_completed timeout (config.PHASE_TIMEOUT_S): a hung sim is
    recorded as a failure and the pool rebuilt instead of freezing the whole run.
    - Use mkdtemp for per-sim temp dirs (collision-proof)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
    [config.py]
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2026-06-05 fix sending functions
    advances #54
    [main.cpp, utility.cpp]
2026-06-05 Add buzzerSound, buzzerSoundError, loopVariablesUpdate, ledUpdate, ledStruct
    [main.cpp, utility.cpp]
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2026-06-06 rework radio module library
    include serial functions and rework function and attribute naming. fixes #54
    [main.cpp, utility.cpp]
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2026-06-07 Patch antenna: research docs & BOM
    Design research notes, migration plan, and bill of materials for the flat dual-feed branch-line-coupler patch, plus WIP status.
    [bom.csv]
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2026-06-07 Patch antenna: NF2FF efficiency / realised-gain rework + directivity units fix
    Implement the parked efficiency analysis, and fix two validated issues it exposed.
    Findings (dipole-calibrated, power-balance closes to 100%):
    - Directivity units bug: openEMS nf2ff.Dmax is a LINEAR ratio, not dBi. Reporting it
    raw under-read directivity by 10*log10 -- true boresight is 5.9 dBi, not 3.9.
    - Radiation efficiency is real, not an NF2FF artefact: the patch radiates only ~3% of
    accepted power (realised gain ~-9.6 dBic). A 150k iso-resistor probe decomposition
    gives 64% isolated-resistor / 33% FR-4 dielectric / 3% radiated -- the branch-line
    coupler dumps the feed-point mismatch into the isolate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
    [config.py]
2026-06-07 Patch antenna: migrate dual-feed coupler → single-feed corner-truncated CP
    Replace the branch-line-coupler dual-feed RHCP patch with a single-feed corner-
    truncated patch. The coupler dumped ~64% of accepted power into its isolated-port
    resistor (realised gain -9.6 dBic); deleting it recovers that power.
    Validated (150k at the proven warm-start dims, from the old single-feed branch
    re-scaled to NP-140F er 4.15): eta_rad 3.1% -> 28.4%, realised gain -9.6 -> +0.8 dBic,
    RHCP, S11 -10.9 dB. AR is 6.2 dB at the un-tuned seed (the W x truncation optimiser
    centres the AR null on f_target; corner-truncated patches reach AR < 1 dB tuned).
    CP now from truncating two diagonal corners (chamfer; BLTR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
    [config.py]
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2026-06-08 Patch antenna: optimise the AR NULL, not the S11 centroid (+ fix AR-vs-f smoothing)
    The full optimise + NF2FF analysis of the saved sim_data exposed two coupled bugs
    that made a GOOD CP design read as bad and steered the optimiser the wrong way.
    ROOT CAUSE: the CP axial-ratio null sits ~7 MHz BELOW the S11 centroid - a matched
    patch is NOT automatically circular at f_target. Measured on real 150k sim_data:
    W=82.5 -> AR null 869.0 MHz, AR @ f0 0.45 dB, AR<=3 BW 8 MHz (~perfect, on target)
    W=83.05 -> AR null 863.5 MHz, AR @ f0 4.63 dB (null pushed off)
    So the seed W=82.5 was already optimal; centring the S11 centroid (the previous grid
    recentre) de-centred the CP.
    -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
    [config.py]
2026-06-08 Patch antenna: harden AR-null optimiser per adversarial review
    Adversarial multi-agent review of the AR-null fix confirmed one bug and surfaced cheap
    consistency hardening (the verified-not-real findings are addressed too as they are low-risk):
    - optimizer: per-phase hang guard now scales with the actual per-host work
    (max(PHASE_TIMEOUT_S, 4x waves x per-sim)), not a fixed 3 h calibrated to the 20-thread
    reference host - a slow/few-core box running 3 serial 150k waves was wrongly marked a
    timeout failure. [confirmed bug]
    - optimizer: the worker AR-null scan now uses MEAN-over-phi at the theta=2 deg ring (the
    same aggregation postproc._axial_ratio_sweep uses, so opt and final locate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
2026-06-08 Patch antenna: document the AR-null finding + correct AR claims in research/WIP
    The single-feed seed (W=82.5/trunc=8.25/inset=5.8) already meets CP - AR 0.45 dB at f0,
    AR<=3 over a 180 deg beam, 8 MHz CP bandwidth. The earlier "AR ~6 dB, needs tuning" was a
    post-processing artefact (25 MHz boxcar over a few-MHz null), not the antenna.
    - research.md: TL;DR + finding #4 corrected to the real AR (0.45 dB, seed = final design);
    new finding #0.6 documents that the CP AR NULL sits ~7 MHz BELOW the S11 centroid (so a
    matched patch is not auto-circular - optimise the null, not resonance) with the measured
    W=82.5 vs 83.05 table and the two bugs fixed; §9 decision table + notes updated; stale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
2026-06-08 Patch antenna: guard against empty NF2FF (zero far-field) in the optimiser worker
    The verification optimise exposed a resource limit: 9 concurrent sims at NrTS=150k returned
    EMPTY NF2FF (Prad~0, Dmax~0, AR=-inf) while the port S11 stayed valid - the openEMS NF2FF
    recording scales with NrTS and 9x150k apparently overran RAM/temp-disk (9x60k and 3x150k
    both worked). Those garbage sims returned ok=True with a finite cost (-1.20), which would
    silently pollute grid selection.
    The worker now validates res_f.Prad>0 and Dmax>0; otherwise it returns a failure_result
    (ok=False) so the optimiser excludes the sim. With a whole grid phase tripping this, the
    search falls back to confirming the seed (= th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
2026-06-08 Patch antenna: cap optimiser concurrency at 3 (NF2FF-safe) + RHCP sense confirmed
    Full optimise re-run converged cleanly to the verified optimum W=82.5/trunc=8.25/inset=5.8:
    AR 0.45 dB @ 869.525, AR-null on 869.0 MHz, AR<=3 over a 180 deg beam (7.5 MHz CP BW),
    S11 -12, directivity 6.6 dBi, eta_rad 28.3%, realised +0.8 dBic, RHCP. The grid AR nulls
    bracket the optimum (W 82.0->+5 / 83.0->-5 MHz; trunc 6.5->-3 / 10->+3 MHz), so the
    corrected AR-null objective selects 82.5/8.25 on its own (cost -4.52).
    - config.MAX_WORKERS 9 -> 3: at NrTS=150k, 9 concurrent sims overran a RAM/temp-disk limit
    and returned EMPTY NF2FF; 3-concurrent x 150k runs clean (each sim gets ~6 threads, so the
    9-sim gr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
    [config.py]
2026-06-08 Patch antenna: report realised cone-edge gain, de-stale link tool, add eps-robustness sweep + gates
    Post-adversarial-review honesty/correctness fixes (design unchanged; these correct how it is
    reported and add the missing pre-fab de-risk):
    - tests/tool_link_budget.py: was STALE (modelled the retired dual-feed at -9.6 dBic). Rewritten
    for the single-feed realised gains (+0.84 boresight, -2.0 cone-edge) and aligned to
    linkbudget.ipynb (G_TX -5, P_RX -114, L_TX+L_RX 6) so the two agree; margin tiers per the
    notebook. Closes the 10 dB floor across the helical 18.4 km (+19.6/+16.8 @10 km, +14.3/+11.5
    @18.4 km) but not the 30 dB target - expected for a backup.
    - src/postproc.py: results.j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
    [bom.csv]
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2026-06-08 Patch antenna: centre top description on patch; move Patch/trunc labels to patch bottom-right; fix center-justify
    [patch_antenna-B_Courtyard.gbr, patch_antenna-B_Cu.gbl, patch_antenna-B_Mask.gbs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]
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2026-06-13 rework onboard firmware to fix several bugs
    [main.cpp, utility.cpp]
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2026-07-07 Patch antenna: sealed printable enclosure + 350k datasheet & thermal/trunc results
    Squash of the enclosure + datasheet work on this branch:
    - casing/: parametric OpenSCAD enclosure (rev C) - all-nylon standoffs, debossed
    branding + sunburst, beveled bezel + R10 corners, DFM/seal build-time asserts
    - datasheet: 350k convergence-proven; 1.6mm corner truncation confirmed optimal
    - record thermal CP-window + add thermal-drift and trunc-bw sweep tools/results
    - archive old logos; add KiCad project file (fab/patch_antenna.kicad_pro)
    - portability: deco_svg is now relative to the .scad (no host absolute path);
    ignore machine-local .mcp.json
    [enclosure.scad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]
2026-07-07 Groundstation GUI: fix packet framing, DPG thread-safety, shutdown + hardening
    Frame telemetry per cycle so dropped RF lines no longer blend two packets; marshal all map DPG mutations to the main thread; fix Escape/exit lifecycle and stop background threads on shutdown; apply saved thresholds live; per-event abort flag; DMS sign/carry; signed/fractional regex; assorted robustness and leak fixes.
    [acceleration_window.py, altitude_window.py, battery_window.py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]
2026-07-07 Groundstation GUI: address issue #45 UI feedback
    Unified Stop/Reset across all plots via a coordinator; arm resets plots + mission clock, disarm clears flight events (no lingering Armed); per-source GNSS min/max/current; new Subsystem Status box (red/green per bit); time-since-last-packet shown in Connection; consistent yellow box headings; baud-rate dropdown; UTF-8-safe console logging.
    [acceleration_window.py, altitude_window.py, battery_window.py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]
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2026-07-07 Groundstation GUI: finish issue #45 (+UI symbols, font cleanup)
    Δ for acceleration delta/median-delta; ⚠ prefix on WEAK SIGNAL / UNDERVOLTAGE warnings; ✓ done / ⚠ ABORT flight-event states; ✓ Send / ✗ Abort command buttons.
    Fixes #45
    [acceleration_window.py, battery_window.py, commands_window.py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]
2026-07-12 several documentation improvements
    fixes #52 fixes #53 | Add sensorics subsystem flash commands | Update packet structure documentation | Update operations cheatsheet documentation | Fix documentation bugs
    [i2c_connectivity.cpp, utility.cpp]
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2026-07-12 rework 869 MHz helix design
    update to a much smaller version
    [Antenna Assembly.f3z, Antenna Assembly.step, Bottom Cone.step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]
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2026-07-14 add motherboard casing
    fixes #27
    [Casing Bottom.step, Casing Bottom.stl, Casing Shell.stl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]
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2026-07-21 add lowPowerMode pointer in ledStruct fix #55
    [main.cpp, utility.cpp]
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2026-07-25 fix several bugs in onboard and groundstation firmware and in the packet library
    [i2c_connectivity.cpp, main.cpp, utility.cpp]
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2026-08-10 fixes several bugs for onbaord and groundstation
    [main.cpp, utility.cpp]
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2026-08-11 include qfh cad tutorial
    fixes #59
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2026-08-24 Patch antenna: docs/code cleanup + JLCPCB fab doc, gerber export tool & stale-gerber guard
    research.md: drop bug-narrative and dead-design history; report the converged 350k numbers (fab/results.json); fold in WIP.md, then remove WIP.md. Cut ~286 lines of dead silk-graphics helpers from kicad_export.py (board output byte-identical); condense run-ID archaeology in config/optimizer/params; drop dead SUB_HW_N. enclosure: correct standoffs to all-nylon (stale 'brass heat-set' docs) and restate DFM rules present-tense. bom.csv: printed-enclosure parts. Add docs/fab_order.md (JLCPCB settings + laminate caveat), fab/export_gerbers.ps1 (one-command re-plot+zip) and a pre-commit guard so gerbers cann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
    [bom.csv, enclosure.scad]
2026-08-25 add fixes from last report :)
    [i2c_connectivity.cpp, main.cpp, utility.cpp]
2026-08-26 Patch antenna: fix trunc silk label + single-source-of-truth config
    Silk: front now reads 'trunc 8.25 mm' (was 8.2 — a .1f rounding bug). Regenerate the board as a KiCad-9 file (restores the back datasheet table + deco disc that a KiCad-10 edit had dropped), re-plot gerbers, refresh the upload zip. SoT: config.py freezes the locked geometry, removing the 82.4937-vs-82.5 split; run.py, enclosure.py and kicad_export.py read dims/mounting/connector MPN from config; kicad_export refuses to build a board whose results.json disagrees with config; add tests/test_no_drift.py (config <-> results.json <-> datasheet). Board and gerbers verified byte-identical (output-neutral); enclosure aligned to 82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
    [enclosure.scad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]
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2026-09-08 implement new dynamic packet library in firmware
    fixes #70
    [i2c_connectivity.cpp, main.cpp, utility.cpp]
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2026-09-24 include cad models
    fixes #85
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
